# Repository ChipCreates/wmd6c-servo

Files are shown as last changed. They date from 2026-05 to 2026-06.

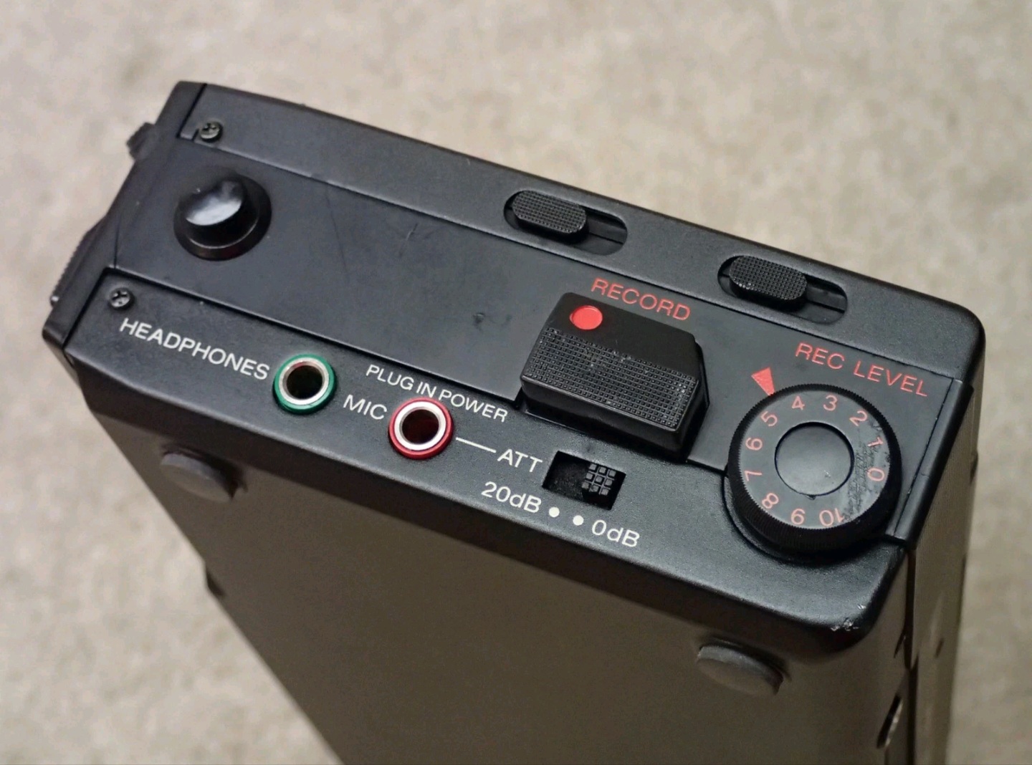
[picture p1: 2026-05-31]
docs/photos/overview/18-record-controls-audio-jacks.jpg

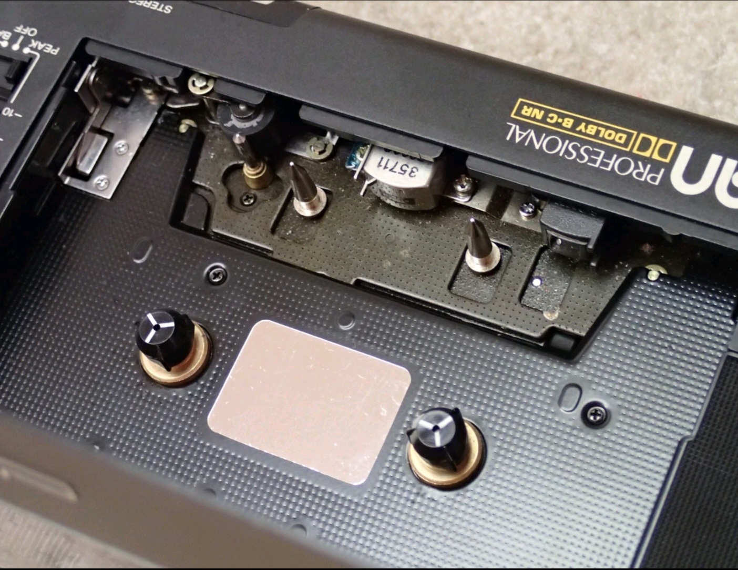
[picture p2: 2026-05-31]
docs/photos/overview/09-tape-mechanism-heads-closeup.jpg

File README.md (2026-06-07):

# wmd6c-servo — DSR-1

**Open-source / open-hardware servo, power, and USB-C service subsystem for the Sony Walkman WM-D6C / TC-D6C**

DSR-1 is an in-development replacement and modernization subsystem for the Sony WM-D6C / TC-D6C. Rev A targets the **CX20084 former-type servo family**, with the first physical unit identified as WM-D6C serial `72795`, PCB marking `C11-494-12`, and a surface-mount CX20084 at IC601. Its purpose is to preserve machines by replacing the fragile capstan-servo IC path, modernizing the external power interface, and adding USB-C data/service access for tuning, telemetry, firmware update, and diagnostics.

This project is not yet a finished installation-ready repair. It is currently in **source-grounded design and firmware-prototype development**. The firmware architecture exists, the KiCad files are in-flight and not yet synchronized with the latest documentation, and the design is being revised against the Sony WM-D6C/TC-D6C service manual and the selected STM32G0C1KCU6 device. PCB layout, hardware validation, installation documentation, and performance testing remain pending.

DSR-1 should be understood as an integrated two-board subsystem project, not a servo-only daughterboard: a **Power Board** and a **Servo Control Board**.

---

## Project Intent

The Sony WM-D6C is a professional-grade portable cassette recorder with a quartz-lock capstan servo system, excellent speed stability, and a transport worth preserving. Many surviving units are threatened by failures in and around the servo and power-input circuitry:

- **CX20084 / IC601 servo failure** — the original capstan-servo IC is obsolete and difficult to source reliably.
- **CN301 external power risk** — the original DC input arrangement is vulnerable to wrong-adapter failures.
- **CP304 / power-support aging** — the surrounding DC-DC and power-support circuitry is now decades old.
- **Serviceability limits** — the original analog servo has limited internal observability and cannot easily expose measured FG period, loop error, correction output, or tuning state.
- **Modern service access gap** — the original machine has no digital tuning, telemetry, firmware update path, or structured diagnostic interface.

DSR-1 aims to make the WM-D6C repairable without reducing it to a generic motor controller. The goal is not to modernize for its own sake. The goal is to preserve the machine by replacing an increasingly fragile control and power-support subsystem with one that can be measured, tuned, documented, powered safely, and reproduced.

---

## Current Status

**Status: active design / firmware prototype. Not bench-validated. Not ready for installation in a valuable machine.**

| Area | Status |
|---|---|
| Architecture | Defined at a high level |
| Sony service-manual review | In progress |
| STM32G0C1KCU6 package/pinout review | Accepted baseline; firmware migration pending |
| Firmware prototype | Register-level C source exists; bench validation pending |
| USB-C data/service path | Design requirement; validation pending |
| USB-C PD / power path | First-class design requirement; final implementation pending |
| KiCad schematic | In-flight legacy project exists; manual split to Power Board and Servo Control Board pending |
| PCB layout | Not complete |
| Bench measurements | Required before Rev A finalization |
| Installation guide | Planned; not yet valid for users |
| Pre-built module | Not available |
| Performance claims | Pending measured speed, power, USB, and wow/flutter data |

Until the electrical interface is measured on a real WM-D6C and a Rev A board is validated, DSR-1 should be treated as an engineering project, not a repair product.

---

## Compatibility Scope

DSR-1 targets the **full WM-D6C / TC-D6C production run (1984–2002)**. Two servo circuit families exist:

| Circuit family | Years | Servo IC | Rev A status |
|---|---|---|---|
| Ver. 1.0 | 1984 – mid 2001 | CX20084 | **Primary Rev A target** |
| Ver. 1.1 | mid 2001 – 2002 | CX-069A | Planned post-Rev A variant |

Rev A targets CX20084 boards — the large majority of surviving units. CX-069A board support is planned as a separate variant once Rev A is validated. See `docs/hardware/wmd6c-revision-compatibility.md` for detailed production timeline and identification guidance.

The primary unit currently being mapped is serial `72795`, observed PCB marking
`C11-494-12`, with a surface-mount CX20084 at IC601. Earlier assumptions that this
unit was a through-hole board are superseded.

---

## Governing References

Rev A is being grounded against these primary references:

1. **Sony WM-D6C / TC-D6C Service Manual, original edition (`fb4872.pdf`)**
   - Governing reference for Ver. 1.0 CX20084 servo circuit, component values, board layout, and tape speed calibration procedure.

2. **Sony WM-D6C / TC-D6C Service Manual, Ver. 1.1, 2001.06 (`sony_wm-d6c_tc-d6c_ver-1.1.pdf`)**
   - Documents the 2001 servo circuit change to CX-069A. Reference for Ver. 1.1 variant design (post Rev A).

3. **STMicroelectronics STM32G0C1KCU6 / STM32G0 family documentation**
   - Primary reference for MCU capabilities, electrical limits, package constraints, ADC/timer/USB/UCPD features, and operating conditions.

The repository documentation should distinguish clearly between:

- facts supported by the Sony service manual,
- facts supported by the selected STM32G0C1KCU6 package/device documentation,
- behavior implemented in source code,
- behavior measured on the bench,
- and design goals not yet proven.

---

## Design Position

DSR-1 is now scoped as an integrated two-board subsystem with three first-class domains:

| Domain | Purpose |
|---|---|
| Capstan servo | Replace the obsolete CX20084-based servo path with a measurable digital control loop |
| Power | Power Board for USB-C input, charger, LiPo/protection, regulation, and battery telemetry |
| USB-C data/service | Provide telemetry, live tuning, firmware update, diagnostics, and optional PD negotiation |

The servo loop remains the hardest performance-critical problem, but power and USB-C are not deferred side features. They are part of the Rev A architecture and must be represented in schematics, firmware, verification plans, and documentation.

---

## Known Target Unit Facts

The first physical target is a **former-type CX20084 WM-D6C**, not the 2001 CX-069A
new-type circuit.

| Machine / board | Current status |
|---|---|
| WM-D6C serial `72795` | Primary physical unit |
| PCB marking `C11-494-12` | Observed on the actual unit |
| IC601 | Surface-mount CX20084 |
| CX-069A boards | Planned post-Rev A variant only |
| WM-D6 | Future variant candidate only |
| WM-D3 / WM-D3C | Future variant candidate only |
| TC-D5M and related Sony professional machines | Future variant candidates only |

A variant port will require a schematic comparison, a harness/interface map, measured FG target data, power-interface notes, USB/service constraints, and proof of operation on physical hardware.

---

## What DSR-1 Is Intended to Replace or Add

The project boundary is larger than the CX20084 alone. The intended Rev A design work concerns the WM-D6C capstan-servo subsystem, the power path required to support it, and a USB-C service/data interface.

| Original function / missing function | DSR-1 design intent |
|---|---|
| CX20084 / IC601 capstan-servo function | STM32G0C1KCU6 digital PI servo loop using timer input capture |
| FG feedback path from motor / FG901 | Protected, conditioned MCU timer-capture input |
| Motor correction output to Sony drive network | PWM + RC filter + NPN level-shift to Q601 base; exact Q601 part/package pending physical confirmation |
| RV601 base speed adjustment | Retained as measured analog input |
| RV602 Speed Tune control | Retained as measured analog input |
| RV603 Speed Tune range control | Retained as measured analog input |
| S601 Speed Tune switch | Retained as digital input, polarity to be verified |
| S801 VU/BATT switch and D801-D805 LEDs | `S801_BATT` enables MCU battery-gauge ownership; MCU drives LEDs only in BATT mode and releases them in VU/non-BATT mode |
| CP304 / supporting power conversion | Replacement or support circuit pending Rev A power design |
| CN301 external power vulnerability | Protected input and/or USB-C power path |
| USB service interface absent in original | USB CDC / DFU / diagnostics / telemetry |
| USB-C PD absent in original | Power negotiation strategy, implementation pending |

The original transport, heads, audio path, user controls, and mechanical adjustment procedures should remain intact wherever possible.

---

## Architecture Overview

DSR-1 is designed around an STM32G0C1KCU6 microcontroller running register-level bare-metal C.

Planned/implemented firmware architecture:

- **FG measurement:** TIM2 input capture measures the period between FG pulses.
- **Servo loop:** PI control calculates motor correction from measured period error.
- **Output stage:** TIM3 PWM filtered through an RC network and NPN level-shift transistor (Q_LS MMBT3904) drives Q601's base on the WM-D6C main board.
- **Speed controls:** RV601/RV602/RV603 and S601 are retained and read by the MCU after voltage-safety verification.
- **USB data/service:** USB CDC is intended to expose live tuning, telemetry, command/status reporting, and diagnostics.
- **Firmware update:** USB DFU or other update path is intended to avoid requiring permanent SWD access after installation.
- **USB-C / power:** CC1/CC2 map to PA8/PA9. Variant A may use PD support; the battery build uses plain 5V USB-C into the Power Board charger.
- **Battery indicator:** In the battery build, the MCU reads `VBAT_SENSE`, `CHG_STAT`, `PGOOD`, and `S801_BATT`; it drives `BATT_LED1-5` only while S801 is in BATT.
- **Persistence:** Tuned constants are intended to be saved to flash with validation.
- **Debugging:** SWD remains available during development.

Important design caveat: the target period stored in flash is numerically stable, but final speed accuracy depends on the MCU timebase. The STM32 internal oscillator is suitable for firmware development, but final speed-performance claims require either a proven timing strategy, an external reference, calibration, or measured evidence that the selected clocking approach meets the WM-D6C speed requirements across realistic conditions.

---

## Rev A Engineering Priorities

The next project milestone is a source-grounded electrical interface and a bench-measured Rev A design covering servo, power, and USB-C.

Required before Rev A PCB finalization:

1. Map every DSR-1 signal to a Sony service-manual reference or a DSR-1-only service function.
2. Measure FG901 waveform voltage, offset, edge shape, noise, and frequency at correct speed.
3. Measure Q601 / motor-drive control voltage range during stop, startup, and play.
4. Measure RV601, RV602, and RV603 wiper voltage ranges and source behavior.
5. Verify S601 Speed Tune switch logic polarity and voltage.
6. Verify CN301 / battery / CP304 rail behavior under startup and play load.
7. Define the USB-C data/service connector role, ESD protection, shield/ground strategy, and firmware mode behavior.
8. Verify the S801 BATT-position sense, LED polarity/current limits, and CX10043 high-Z/release behavior before MCU LED ownership is finalized.
9. Decide the final servo timebase strategy.
10. Split and repopulate the KiCad schematic into the Power Board and Servo Control Board projects from measured interface requirements.
11. Validate power rails, reverse-polarity protection, USB enumeration, DFU/update behavior, and servo loop behavior before real-machine installation.
12. Publish measured speed, wow/flutter, power, and USB validation results before claiming original-equivalent or improved performance.

---

## Power and USB-C Strategy

Power and USB-C are part of the project scope.

| Function | Rev A intent |
|---|---|
| Protected external power | Required |
| Reverse-polarity protection | Required |
| Overcurrent / fault protection | Required |
| USB-C connector | Required for service/data; power role to be finalized |
| USB CDC telemetry | Required design goal |
| Firmware update path | Required design goal |
| USB-C PD | First-class design requirement; implementation architecture pending |
| Original barrel jack retention | Optional variant decision |
| CN301 replacement/removal | Optional variant decision |

Possible power approaches:

| | USB-C-centered variant | Protected barrel / hybrid variant |
|---|---|---|
| Power input | USB-C power path with PD strategy | Original-style or lab/protected input retained |
| User-facing behavior | Modern external power and data through USB-C | More conservative power bring-up |
| Complexity | Higher | Lower |
| Project status | In scope | In scope |

The preferred architecture should be selected by schematic feasibility, pin availability, installation constraints, safety behavior, and bench validation—not by minimizing scope.

---

## Repository Structure

```text
wmd6c-servo/
├── hardware/        KiCad project, schematic work, future PCB/BOM/gerbers
├── firmware/        Bare-metal STM32G0 family firmware prototype
├── docs/            Theory, datasheet references, installation and validation docs
└── tools/           Calibration and development utilities
```

Some paths and build commands are still being normalized as the project moves from design notes into a reproducible hardware/firmware package.

---

## Firmware Development

The firmware is written in C for the STM32G0 family, using CMSIS device headers and direct register access. The hardware target is STM32G0C1KCU6; some firmware filenames and comments may still reflect the earlier STM32G0B1KBU6 prototype until the firmware migration is completed. No STM32 HAL, no RTOS, and no dynamic memory allocation are intended.

Current firmware areas:

- `main.c` — clock setup, peripheral initialization order, main loop
- `servo.c` / `servo.h` — TIM2 capture ISR, PI loop, TIM3 PWM output path
- `adc.c` / `adc.h` — speed-control potentiometer scan and target adjustment support
- `flash.c` / `flash.h` — persistent settings storage
- `usb_cdc.c` / `usb_cdc.h` — USB CDC command and telemetry path
- `config.h` — tunable constants and hardware-selection flags

Firmware areas now required by project scope:

- USB CDC service and telemetry must remain isolated from the real-time servo loop.
- USB DFU or equivalent firmware update path must be documented and tested.
- USB-C attach/power-role behavior must be specified.
- If native STM32 UCPD is used, PD firmware must not compromise servo timing.
- If an external PD controller is used, firmware must define any required monitoring/control interface.
- Battery-gauge firmware must treat `S801_BATT` as the LED ownership enable and keep `BATT_LED1-5` released in VU/non-BATT modes.

Current firmware caveats:

- Bench validation has not yet been completed.
- The adjusted-target path from the analog speed controls must be verified end-to-end.
- The timebase decision remains open.
- USB-C PD implementation architecture remains open.
- Build layout and CI should be normalized before outside contributors rely on the firmware package.

See the firmware README for current build notes.

---

## Documentation Plan

The repository should grow toward the following documentation set:

```text
docs/
├── hardware/
│   ├── wmd6c-interface-contract.md
│   ├── wmd6c-revision-compatibility.md
│   ├── power-usb-c-architecture.md
│   └── timebase-decision.md
├── theory/
│   ├── original-servo-circuit.md
│   ├── digital-pll-servo.md
│   ├── signal-chain-analysis.md
│   └── power-supply-design.md
├── verification/
│   ├── 00-rev-a-bringup-checklist.md
│   ├── 01-wmd6c-preinstall-measurements.md
│   ├── 02-fg901-waveform-capture.md
│   ├── 03-motor-drive-characterization.md
│   ├── 04-speed-calibration-procedure.md
│   ├── 05-wow-flutter-test-plan.md
│   ├── 06-power-fault-test-plan.md
│   └── 07-usb-c-data-pd-test-plan.md
└── installation/
    └── planned after Rev A validation
```

Installation documentation should not be treated as valid until the hardware has been built, tested, photographed, and verified against the Sony adjustment procedure.

---

## Contributing

Contributions are welcome, but the project is still early enough that measurements and source-grounded review are more valuable than feature additions.

Most useful contributions right now:

- WM-D6C board-revision identification and photographs.
- Clear scans or notes that distinguish former/new servo circuit revisions.
- Bench measurements of FG901, Q601 motor-control behavior, RV601/RV602/RV603, S601, CP304, CN301, and original power rails.
- STM32G0C1KCU6 pinout and package review for servo, USB, UCPD, SWD, ADC, PWM, and timer conflicts.
- USB-C PD architecture review, including native UCPD versus external controller tradeoffs.
- Firmware review focused on interrupt timing, timer capture, ADC safety, flash behavior, USB CDC isolation, and PD interaction.
- KiCad schematic review once the Rev A sheets are populated.

Please see [CONTRIBUTING.md](CONTRIBUTING.md) for contribution expectations.

---

## License

| Artifact | License |
|---|---|
| Hardware design files | [CERN OHL-P v2](LICENSE_HARDWARE.txt) |
| Firmware source | [MIT](LICENSE) |
| Documentation | [CC BY 4.0](LICENSE_DOCS.txt) |

---

## Project Position

DSR-1 is being developed as a preservation-oriented engineering project. Its purpose is to make the WM-D6C repairable, measurable, maintainable, safely powered, and digitally serviceable without erasing what made the original machine worth saving.

Performance and safety claims will be earned by measurement, not assumed from architecture.

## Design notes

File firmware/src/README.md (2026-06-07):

# DSR-1 Firmware

Bare-metal C firmware for the WM-D6C DSR-1 Servo Control Board. The project
hardware target is STM32G0C1KCU6 at 64 MHz; this firmware tree still carries some
legacy STM32G0B1 build filenames until the firmware migration is completed. No HAL,
no RTOS, no dynamic memory allocation.

---

## Source Files

| File | Responsibility |
|---|---|
| `config.h` | All tunable constants — edit here and rebuild |
| `servo.c` / `servo.h` | TIM2 input capture ISR, PI control law, TIM3 PWM output |
| `adc.c` / `adc.h` | ADC DMA scan for RV601/RV602/RV603 pot wipers |
| `flash.c` / `flash.h` | Settings save/restore with CRC-32 validation |
| `usb_cdc.c` / `usb_cdc.h` | USB CDC virtual COM port, command parser, telemetry |
| `main.c` | Clock init (HSI16 → 64 MHz PLL), peripheral sequencing, main loop |

Build files live in `firmware/build/`:

| File | Responsibility |
|---|---|
| `Makefile` | `arm-none-eabi-gcc` build, flash/DFU targets |
| `STM32G0B1KBUx_FLASH.ld` | Legacy prototype linker script — to be replaced for STM32G0C1KCU6 |
| `startup_stm32g0b1xx.s` | Legacy prototype CMSIS startup — to be replaced for STM32G0C1KCU6 |

---

## Prerequisites

**Toolchain:** `arm-none-eabi-gcc` version 10.0 or newer.

```bash
# macOS
brew install --cask gcc-arm-embedded

# Ubuntu / Debian
sudo apt install gcc-arm-none-eabi

# Windows
# Download from https://developer.arm.com/downloads/-/gnu-rm
```

**CMSIS headers:** The STM32G0 CMSIS device headers (`stm32g0b1xx.h` etc.) must be on the include path. The Makefile searches three standard locations automatically. If not found, either:

- Set `CMSIS_DIR` on the command line (see below), or
- Copy the headers into `firmware/cmsis/` and the Makefile will find them

The headers ship with the [STM32CubeG0 package](https://www.st.com/en/embedded-software/stm32cubeg0.html) under `Drivers/CMSIS/`.

---

## Building

```bash
cd firmware/build

# Standard build — produces firmware.elf, firmware.bin, firmware.hex
make

# With explicit CMSIS path
make CMSIS_DIR=/path/to/STM32Cube_FW_G0_V1.6.1/Drivers/CMSIS

# Flash via SWD (requires openocd)
make flash

# Flash via USB DFU (device must be in DFU mode — hold TP1/BOOT0 while connecting USB)
make dfu

# Print section sizes
make size

# Generate annotated disassembly
make disasm

# Clean all build artefacts
make clean
```

The build prints a flash usage summary on completion. At the current firmware size of ~28 KB, there is approximately 98 KB of headroom against the 126 KB firmware budget (the last 2 KB page is reserved for the settings sector).

---

## Configuration

**`config.h` is the only file you should need to edit for normal configuration.** All machine-specific values, gain constants, and hardware limits are defined there. Never scatter tunable values through source files.

### Critical: TARGET_PERIOD_DEFAULT

This constant must be measured on the bench — the placeholder value will not be correct for every unit.

1. Insert test tape WS-48B, select Play mode
2. Connect oscilloscope to LINE OUT
3. Confirm 3 kHz tone = correct speed
4. Measure FG901 pulse frequency at that speed
5. Set `TARGET_PERIOD_DEFAULT = 64000000 / measured_Hz`
6. Rebuild and flash

Alternatively, use the `f+` / `f-` USB CDC commands to tune in real time without rebuilding, then `s` to save.

### Motor Output Stage

DSR-1 uses the **PWM + RC filter + NPN level-shift** output stage exclusively.
On the primary WM-D6C serial 72795 unit, Q601 is on the surface-mount
`C11-494-12` board and its exact package/marking plus base operating range remain
pending bench verification. Direct DAC drive is not used.

TIM3 channel 1 on PA6 produces the PWM signal. There is no `SERVO_OPTION_B`
define — the firmware is committed to this single output topology.

---

## USB CDC Live Tuning

The module enumerates as a virtual COM port on any computer without driver installation. Connect with any serial terminal at any baud rate (the baud rate setting is ignored — it is a USB CDC device).

| Command | Effect |
|---|---|
| `p+` / `p-` | Adjust Kp ±0.01 |
| `i+` / `i-` | Adjust Ki ±0.001 |
| `f+` / `f-` | Adjust target period ±1 tick |
| `t` | Print telemetry snapshot |
| `T` | Toggle continuous telemetry |
| `s` | Save current constants to flash |
| `r` | Restore compiled-in defaults (SRAM only — does not write flash) |
| `?` | Print command reference |

On first connection the firmware sends a banner confirming whether saved flash settings were loaded or defaults are active. If the banner shows a corruption warning, calibrate the unit and send `s` before use.

### Telemetry format

```
FG:25612 Hz:2499 Tgt:25600 Err:+12 Int:-847 PWM:2034 Kp:9830(0.150) Ki:524(0.008) RV1:2048 RV2:1923 RV3:2100
```

---

## Firmware Update (DFU)

The intended STM32G0C1KCU6 target contains a factory-programmed USB DFU bootloader.
To enter DFU mode:

1. Hold BOOT0 test point (TP1) to VDD
2. Connect USB-C cable
3. Release TP1

The device enumerates as a DFU device. Flash with:

```bash
# Using dfu-util (macOS/Linux)
dfu-util -d 0483:df11 -a 0 -s 0x08000000:leave -D firmware.bin

# Using STM32CubeProgrammer (Windows/macOS/Linux GUI)
# Select the .bin file, click Download
```

Pre-built `.bin` files for each release are in `firmware/releases/`.

> **Settings are preserved across DFU updates.** The settings sector (last 2 KB page at `0x0801F800`) is not erased by the update process.

---

## Architecture Notes

**Interrupt priorities** (lower number = higher priority on Cortex-M0+):

| Priority | Interrupt | Constraint |
|---|---|---|
| 0 | TIM2 (servo ISR) | Must preempt everything — non-negotiable |
| 1 | USB | Must not delay servo |

**Flash writes during playback:** The `s` command calls `servo_freeze()` before erasing flash and `servo_unfreeze()` after. The motor runs at constant open-loop drive for the ~2 ms erase window; the flywheel time constant (~200 ms) means speed does not measurably change. The servo re-locks within 1–2 FG periods after the write completes.

**No heap:** All memory is statically allocated. `_Min_Heap_Size = 0` in the linker script. `malloc` is not available and must not be added.

**Contributor rule:** All firmware contributions must use register-level C only. The STM32G0x1 Reference Manual (RM0444) and the selected STM32G0C1KCU6 datasheet are the authoritative sources — not the HAL API. See `docs/theory/why-bare-metal.md` for the full rationale.

---

## Licence

Firmware: MIT — see `LICENSE_FIRMWARE.txt`

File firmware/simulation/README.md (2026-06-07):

# DSR-1 Renode Simulation

Renode-based simulation for the DSR-1 firmware. The simulation platform still
models the earlier STM32G0B1 prototype until the firmware tree is migrated to the
STM32G0C1KCU6 hardware target.
Run from the **workspace root** (`d:/Projects/wmd6c-servo`).

## Prerequisites

**1. Install Renode** from https://renode.io. Packages are available for all
major platforms:

| Platform | Package |
|---|---|
| Windows | `.msi` installer (winget: `Antmicro.Renode`) |
| macOS | `.pkg` installer |
| Ubuntu / Debian | `.deb` — `sudo dpkg -i renode_*.deb` |
| Fedora / RHEL | `.rpm` — `sudo dnf install renode_*.rpm` |
| Any Linux | AppImage — `chmod +x renode_*.linux-portable` |

**2. Install renode-test Python dependencies.**

*Windows* — the default install path contains a space and must be quoted:
```
pip install -r "C:\Program Files\Renode\tests\requirements.txt"
```

*macOS / Debian / Ubuntu* — Renode installs to a path without spaces:
```
pip3 install -r /opt/renode/tests/requirements.txt
# macOS: /Applications/Renode.app/Contents/MacOS/tests/requirements.txt
```

*Fedora / RHEL* — same as Debian/Ubuntu but confirm the install prefix first:
```
renode --version          # shows install path
pip3 install -r /opt/renode/tests/requirements.txt
```

**3. Verify tools are on PATH** by opening a new terminal and running:
```
renode --version
renode-test --help
```

### VS Code terminal note (Windows only)

On Windows, VS Code's integrated terminal inherits the PATH from when VS Code
was launched, so tools installed afterward won't be found until VS Code is
restarted. The workspace `.vscode/settings.json` works around this for Windows
by appending the tool paths to every new VS Code terminal — open a **new
terminal** (`Ctrl+Shift+`\``) rather than reusing an existing one.

On Linux and macOS the system PATH is read fresh by each terminal and this is
not an issue.

## Quick start — interactive session

```
renode firmware/simulation/scripts/dsr1.resc
```

The Renode monitor (console) opens. The firmware is loaded and halted.

> **Do not call `start`.** The FG macros use `emulation RunFor` internally to
> advance simulation time in controlled steps. Calling `start` puts the emulation
> into free-run mode, which conflicts with `RunFor` inside a macro.

Load the FG helper and inject pulses — the macros start the CPU themselves:

```
(monitor) i @firmware/simulation/scripts/fg-gen.resc
(monitor) runMacro $fg_lock       # 10 nominal-speed pulses
(monitor) sysbus ReadDoubleWord 0x40000434   # read TIM3->CCR1 (motor PWM)
```

Each `runMacro $fg_lock` call steps the firmware through 10 FG edges, running
`clock_init` → `flash_load` → `adc_init` → `servo_init` → servo ISR on the way.
Expected TIM3->CCR1 ≈ 2048 (DAC_CENTER) when FG rate matches target exactly.

## Automated tests (Robot Framework)

```
renode-test firmware/simulation/tests/servo_loop.robot
```

Five tests:
1. **Boot completes** — firmware boots without hanging in any polling loop
2. **Nominal speed** — TIM3->CCR1 stays near DAC_CENTER at target FG rate
3. **Too slow** — motor drive increases (PWM decreases) when FG period is 110%
4. **Too fast** — motor drive decreases (PWM increases) when FG period is 90%
5. **Clamp check** — output stays within DAC_MIN/DAC_MAX at 200% slow
6. **Filter check** — sub-threshold periods (<6400 ticks) are discarded

## VS Code debugging

1. Start the Renode simulation (`dsr1.resc`), which opens GDB server on port 3333.
2. In VS Code: **Run → Start Debugging** → select **DSR-1: Debug via Renode**.
3. Set breakpoints in `servo.c`, `adc.c`, etc.
4. Use the Renode monitor alongside to inject FG pulses.

## FG injection reference

The servo ISR (`TIM2_IRQHandler`) reads `TIM2->CCR1` on every FG rising edge
and computes `period = CCR1 - last_capture`. To simulate one FG pulse from the
Renode monitor:

```
# Write a captured timestamp into CCR1 and fire the TIM2 IRQ
sysbus WriteDoubleWord 0x40000034 <CCR1_VALUE>   # TIM2->CCR1
sysbus WriteDoubleWord 0x40000010 0x00000002      # TIM2->SR: set CC1IF
sysbus WriteDoubleWord 0xE000E200 0x00008000      # NVIC_ISPR0: set IRQ 15 pending
```

Key values (see `firmware/src/config.h`):

| Constant | Value  | Meaning |
|---|---|---|
| TARGET_PERIOD_DEFAULT | 25600  | 2500 Hz at 64 MHz — nominal speed  |
| MIN_PERIOD_TICKS | 6400 | periods shorter than this filtered |
| DAC_CENTER | 2048 | TIM3 PWM at quiescent drive |
| DAC_MIN | 100 | maximum motor drive clamp |
| DAC_MAX | 3995 | minimum motor drive clamp |

To read the current motor PWM output:
```
sysbus ReadDoubleWord 0x40000434    # TIM3->CCR1
```

## Pot trim simulation

> **Note:** `SetVoltage` is not available on all Renode versions. Check with
> `help sysbus.adc` in the monitor. If present, set voltages with:
> ```
> sysbus.adc SetVoltage 1 <voltage>   # RV601 — base speed trim (PA1/ADC_IN1)
> sysbus.adc SetVoltage 2 <voltage>   # RV602 — Speed Tune slider (PA2/ADC_IN2)
> sysbus.adc SetVoltage 3 <voltage>   # RV603 — Speed Tune range (PA3/ADC_IN3)
> ```
> Mid-scale (1.65 V) = no offset. Full deflection (3.3 V or 0 V) = ±1% (RV601)
> or ±3% (RV602 at full range) speed trim.

This is moot until finding §3.3 is resolved — `adc_get_adjusted_target()` has no
caller, so ADC values have no effect on the servo loop in the current firmware.

To simulate the S601 Speed Tune enable switch being pressed (PA7 HIGH):
```
sysbus.gpioPortA SetData 0x0080 0x0080    # set PA7 high
```

## What a green run establishes — and what it does not

A passing run genuinely validates: the firmware boots through `clock_init` →
`flash_load` → `adc_init` → `servo_init` without deadlocking in a polling loop;
the PI arithmetic produces the right output for a given period delta; `DAC_MIN`
/ `DAC_MAX` clamp windup at the rails; `MIN_PERIOD_TICKS` discards short
periods; and the zero-error fixed point sits at `DAC_CENTER`. The control-law
math and structural plumbing are sound.

**Three things it does not establish:**

**1. Motor sign convention** (highest risk). The too-slow / too-fast direction
tests assert that a longer period lowers PWM and a shorter period raises it —
but they check the firmware against its own `config.h` convention with no
motor, no Q601, and no transistor network. If both the convention and the
control law were flipped together the tests would still pass; they were written
to match the code's current intent. Passing them is necessary but not
sufficient. The runaway risk on real silicon is exactly as open as it was before
the simulation existed. See `docs/hardware/motor-drive-sign-convention.md` and
close this only with a bench measurement of Q601 base voltage vs. motor speed.

**2. PA0 alternate function / FG acquisition path**. The simulation injects FG
by writing `TIM2->CCR1` + `CC1IF` + the NVIC pending bit directly, bypassing
the GPIO → AF-mux → input-capture path entirely. The wrong AF produces no
failure in simulation. On hardware, the wrong AF means `TIM2_CH1` is not
connected to PA0 and FG capture silently never fires. Finding 5.2 (PA0 should
be AF2, not AF1) has been fixed in `servo.c`, but the simulation cannot verify
that fix — only the bench can.

**3. Clock frequency correctness**. The RCC Python model releases the polling
loops by toggling ready bits; `PLLCFGR` writes fall through to the catch-all
and are never stored. A malformed PLL configuration (wrong multiplier or
divider) would pass the simulation and fail to lock on hardware. "Clock init
works" is a control-flow result, not a frequency-correctness one. Similarly,
the Renode timer model runs at 10 MHz while the firmware treats ticks as 64
MHz — the period math is internally consistent only because FG is injected as
absolute deltas; absolute timing is untested.

**Bench work the simulation cannot replace:** motor sign (requires Q601
measurement) and the FG acquisition front-end (AF wiring, input-capture
trigger, real FG frequency). These are the least-covered paths and the most
likely sources of a silent hardware failure.

---

## Known simulation limits

| Item | Status | Notes |
|---|---|---|
| Boot / init sequence | Works | All polling loops exit; clock_init, flash_load, adc_init, servo_init complete |
| PI control law | Verified | Period delta → PWM output correct; clamps and filter validated |
| Motor sign convention | **Not validated** | Tests are circular — check firmware against its own convention, not hardware physics; bench measurement required |
| PA0 AF (TIM2_CH1) | **Not caught by sim** | AF2 fix applied to servo.c (finding 5.2); GPIO→capture path never exercised in sim |
| Clock frequency (PLL) | Not validated | RCC model is control-flow only; PLLCFGR ignored; wrong multiplier/divider would pass |
| TIM2 input capture | Manual inject | Renode timer model does not support input capture; fg-gen.resc injects directly |
| TIM3 PWM output | Observable | Read TIM3->CCR1; absolute duty-cycle timing untested (10 MHz model vs. 64 MHz firmware) |
| Flash settings load | Works | Returns FLASH_ERR_INVALID (memory = 0x00), uses defaults |
| ADC calibration / ready loops | Likely works | Depends on STM32G0_ADC model clearing ADCAL and setting ADRDY |
| DMA ADC transfer | Partial | DMAMUX1 tagged; DMA→ADC circular transfer depends on STM32G0DMA model |
| Speed trim path (ADC→servo) | Moot | adc_get_adjusted_target() has no caller (finding 3.3); g_adc_raw[] not populated |
| USB CDC | Stubbed | Replaced with no-op stubs pending G0 USB_DRD port (finding 3.2) |
| Flash erase / write | Not tested | flash_save only reachable via USB CDC command; USB is stubbed |

## Platform file

`platform/stm32g0b1kbu6.repl` is derived from Renode's upstream
`platforms/cpus/stm32g0.repl` with three corrections for the G0B1 die:

- **RAM 144 KB** (upstream has 48 KB for smaller G0 variants)
- **Cortex-M0+** CPU type (upstream says cortex-m0)
- **64 MHz systick** (matching DSR-1 clock_init PLL target; upstream uses 72 MHz)

Plus a `DMAMUX1` tag at 0x40020800 to suppress access warnings from `adc_init`.

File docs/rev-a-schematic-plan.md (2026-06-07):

# Rev A Schematic Plan

**Project:** DSR-1 / wmd6c-servo  
**File:** `docs/hardware/rev-a-schematic-plan.md`  
**Status:** Legacy planning note / superseded by current two-board direction  
**Scope:** Historical schematic-structure planning, design gates, measurement dependencies, and Rev A acceptance criteria. Current implementation is being manually split into a Power Board and Servo Control Board; treat any all-in-one sheet structure below as legacy context unless it agrees with `PROJECT_STATUS.md`.

---

## 1. Purpose

This document defines the Rev A schematic plan for DSR-1.

The goal is to turn the project architecture into a KiCad schematic that can be reviewed, measured against, fabricated, brought up safely, and revised without ambiguity.

DSR-1 is an integrated subsystem project:

1. capstan servo,
2. power input/protection/support,
3. USB-C data/service,
4. USB-C PD or power-role strategy,
5. firmware update/debug,
6. and measurement/test access.

The schematic must reflect all of those domains. It must not be a servo-only schematic with power and USB added casually afterward.

---

## 2. Schematic Design Principles

Rev A schematic work follows these rules:

1. **No unmeasured Sony-facing node is final.**
2. **Every external input needs protection or a documented reason it does not.**
3. **Every motor-control state must fail safe.**
4. **USB-C data and power must not backfeed Sony rails unintentionally.**
5. **SWD/BOOT recovery must remain accessible.**
6. **The selected STM32 package must be proven by pin allocation before routing.**
7. **Every important signal needs a test point or measurement strategy.**
8. **Power, USB, servo, and analog references must be separated intentionally.**
9. **The schematic must encode the bring-up sequence.**
10. **Unsupported options must be marked DNP or moved out of Rev A.**

---

## 3. Required Source Documents

Before schematic acceptance, these documents must exist and be reviewed:

```text
docs/hardware/wmd6c-interface-contract.md
docs/hardware/power-usb-c-architecture.md
docs/hardware/timebase-decision.md
docs/hardware/wmd6c-revision-compatibility.md
docs/stm32g0c1-pin-allocation.md

docs/verification/00-rev-a-bringup-checklist.md
docs/verification/01-wmd6c-preinstall-measurements.md
docs/verification/02-fg901-waveform-capture.md
docs/verification/03-motor-drive-characterization.md
docs/verification/04-speed-calibration-procedure.md
docs/verification/05-wow-flutter-test-plan.md
docs/verification/06-power-fault-test-plan.md
docs/verification/07-usb-c-data-pd-test-plan.md
```

The schematic may begin before all measurements are complete, but any unmeasured area must be clearly marked as provisional.

---

## 4. Proposed KiCad Sheet Structure

Current manufacturing direction:

```text
hardware/power-board/
└── Power Board KiCad project

hardware/servo-control-board/
└── Servo Control Board KiCad project
```

The committed `hardware/kicad/DSR-1` project is in-flight legacy schematic work and
has not yet been updated to match the latest documentation.

---

## 5. Top-Level Sheet

### 5.1 `DSR-1.kicad_sch`

Responsibilities:

- show system-level sheet hierarchy,
- expose major nets,
- make power/servo/USB boundaries obvious,
- avoid hiding cross-domain dependencies.

Top-level net groups:

| Net group | Examples |
|---|---|
| Sony interface | `FG_IN_RAW`, `MOTOR_CTRL_OUT`, `RV601_WIPER`, `RAW_POWER`, `GND` |
| MCU local | `FG_IN`, `MOTOR_PWM`, `USB_DP`, `USB_DM`, `SWDIO`, `SWDCLK` |
| Power | `VBUS`, `RAW_POWER`, `+3V3`, `B_PLUS`, `MOTOR_SUPPLY` |
| USB-C | `USB_DP`, `USB_DM`, `CC1`, `CC2`, `USB_SHIELD` |
| Debug/test | `BOOT0`, `NRST`, `TP_*` |

Rules:

- Major domains must be readable from the top sheet.
- No hidden power nets without labels.
- Every inter-sheet net must use consistent naming.

---

## 6. Power Input / Protection Sheet

### 6.1 `01_power_input_protection.kicad_sch`

Responsibilities:

- external DC input, if retained,
- USB-C VBUS input handoff,
- battery/Sony rail interface,
- reverse-polarity protection,
- overcurrent protection,
- overvoltage protection,
- backfeed prevention.

Required blocks:

| Block | Status |
|---|---|
| CN301/protected external input option | Pending |
| USB-C VBUS input protection | Pending |
| Battery/Sony rail interface | Pending |
| Reverse-polarity protection | Pending |
| Overcurrent/fuse element | Pending |
| TVS/clamp strategy | Pending |
| Ideal diode / power mux strategy | Pending |
| Backfeed prevention | Pending |
| Test points | Required |

Design questions:

- Does USB-C replace CN301 or coexist?
- Does DSR-1 accept original external DC?
- Does DSR-1 support battery operation?
- Which source has priority?
- What rail powers the MCU in service-only mode?

Required test points:

- `TP_VBUS`,
- `TP_RAW_POWER`,
- `TP_PROTECTED_INPUT`,
- `TP_GND_POWER`,
- `TP_POWER_FAULT`.

---

## 7. Power Rails Sheet

### 7.1 `02_power_rails.kicad_sch`

Responsibilities:

- generate 3.3 V logic rail,
- generate or condition motor/support rail if required,
- provide rail sensing,
- provide power-good/fault status,
- ensure safe startup and shutdown.

Required blocks:

| Block | Status |
|---|---|
| 3.3 V regulator | Required |
| Motor/support rail generation or interface | Pending measurement |
| Rail sensing dividers | Recommended |
| Power-good signals | Recommended |
| Fault outputs | Recommended |
| Bulk/local decoupling | Required |
| Analog reference filtering | Required if ADC/PWM-filter sensing is sensitive |

Rules:

- Motor/switching currents must not share sensitive ADC/FG return paths.
- Regulator dropout and thermal behavior must be reviewed.
- Rail-sense dividers must not overvoltage ADC pins.
- DSR-1 must not backfeed Sony rails when unpowered.

Required test points:

- `TP_3V3`,
- `TP_MOTOR_SUPPLY`,
- `TP_B_PLUS`,
- `TP_B_PLUS_3`,
- `TP_GND_ANALOG`,
- `TP_GND_DIGITAL`.

---

## 8. USB-C Data / PD Sheet

### 8.1 `03_usb_c_data_pd.kicad_sch`

Responsibilities:

- USB-C connector,
- USB 2.0 FS D+/D− routing,
- ESD protection,
- VBUS sense/protection,
- CC1/CC2 handling,
- native UCPD or external PD controller,
- USB shield strategy.

Required blocks:

| Block | Status |
|---|---|
| USB-C receptacle | Required |
| D+/D− ESD protection | Required |
| VBUS ESD/protection | Required |
| CC1/CC2 strategy | Required |
| Native UCPD or external PD controller | Open decision |
| VBUS sense | Required |
| USB shield termination | Required decision |
| Service/data path to MCU | Required |

Native UCPD requirements:

- CC1/CC2 routed to valid MCU pins,
- firmware responsibility documented,
- default no-contract behavior safe.

External PD controller requirements:

- controller selected,
- default behavior documented,
- status/control pins assigned,
- output rail protected.

Rules:

- USB shield must not connect accidentally.
- USB ground must not inject motor/audio noise without review.
- USB attach must not enable motor output by default.
- USB D+/D− must be routed as USB signals, not casual GPIO.

Required test points:

- `TP_VBUS`,
- `TP_CC1`,
- `TP_CC2`,
- `TP_USB_DP`,
- `TP_USB_DM`,
- `TP_USB_SHIELD`,
- `TP_PD_STATUS`, if present.

---

## 9. MCU Sheet

### 9.1 `04_mcu_stm32g0c1.kicad_sch`

Responsibilities:

- STM32G0C1KCU6 MCU,
- decoupling,
- reset,
- BOOT0,
- SWD,
- clock/timebase pins,
- all assigned I/O,
- pin labels matching `docs/stm32g0c1-pin-allocation.md`.

Required blocks:

| Block | Status |
|---|---|
| MCU symbol/package | Pending final part |
| VDD/VDDA decoupling | Required |
| VREF+/analog reference handling | Required if used |
| NRST | Recommended |
| BOOT0 access | Required |
| SWDIO/SWDCLK | Required |
| USB pins | Required |
| UCPD pins, if native PD | Conditional |
| ADC inputs | Required |
| TIM3 PWM output (PA6) | Required |
| FG input | Required |
| Timebase option | Pending decision |

Rules:

- MCU package must match final pin-allocation document.
- Do not use family-level assumptions; verify exact package pins.
- SWD and BOOT access must remain available during Rev A.
- Reset/default pin states must not drive motor unsafely.

Required test points:

- `TP_SWDIO`,
- `TP_SWDCLK`,
- `TP_NRST`,
- `TP_BOOT0`,
- `TP_3V3_MCU`,
- selected spare GPIO if available.

---

## 10. FG Input Conditioning Sheet

### 10.1 `05_fg_input_conditioning.kicad_sch`

Responsibilities:

- accept raw FG signal from Sony motor/FG source,
- protect MCU input,
- condition waveform for timer capture,
- reject overvoltage/noise,
- support probing.

Possible blocks:

| Block | Use if |
|---|---|
| Series resistor/clamp | Mild protection sufficient |
| Divider | FG amplitude exceeds MCU range |
| Schmitt buffer | Edges are slow/noisy |
| Comparator | Analog waveform or shifting threshold needed |
| RC filter | High-frequency noise/ringing present |
| Pull-up/down | Source requires defined idle state |

Required input:

- result of `02-fg901-waveform-capture.md`.

Rules:

- Do not finalize conditioning without waveform measurements.
- Do not assume direct MCU input is safe.
- FG input must remain safe if Sony is powered and DSR-1 is unpowered.
- FG input must not load the original circuit significantly.

Required test points:

- `TP_FG_RAW`,
- `TP_FG_CONDITIONED`,
- `TP_FG_GND`.

---

## 11. Motor-Control Output Sheet

### 11.1 `06_motor_control_output.kicad_sch`

Responsibilities:

- generate motor-control correction signal,
- protect Sony motor-control node,
- protect STM32,
- provide safe reset/default state,
- implement PWM + RC filter + NPN level-shift output stage.

**Committed output architecture for Ver. 1.0 CX20084 boards:**

PWM + RC filter + NPN level-shift (TIM3_CH1 PA6 → R7/C8 → Q_LS MMBT3904 →
R9 pullup to B+1 → Q601 base). Q601 exact part/package and base operating range on
the C11-494-12 SMD board remain pending bench verification. Direct DAC drive is not
used.

Ver. 1.1 CX-069A board motor output architecture is not yet characterized and
is out of scope for Rev A.

Required input:

- result of `03-motor-drive-characterization.md`.

Rules:

- Motor output must be safe with MCU reset.
- Motor output must be safe in BOOT0/DFU mode.
- Motor output must be safe during USB attach/PD negotiation.
- Motor output must not backfeed Sony or MCU rails.
- Full output range must be testable with dummy load before Sony connection.

Required test points:

- `TP_MOTOR_CTRL_OUT`,
- `TP_MOTOR_CTRL_RAW`,
- `TP_MOTOR_ENABLE`,
- `TP_MOTOR_GND`.

---

## 12. Speed Controls / ADC Sheet

### 12.1 `07_speed_controls_adc.kicad_sch`

Responsibilities:

- accept RV601, RV602, RV603 wiper signals,
- accept S601 Speed Tune state,
- protect/scalefor MCU inputs,
- filter noise,
- preserve original behavior where practical.

Required signals:

| Signal | Function |
|---|---|
| `RV601_WIPER` | Base speed calibration |
| `RV602_WIPER` | User Speed Tune |
| `RV603_WIPER` | Speed Tune range |
| `S601_SPEED_TUNE` | Speed Tune enable |

Rules:

- No wiper connects directly to ADC until voltage range is measured.
- If source impedance is high, choose sampling time or buffer accordingly.
- Open/dirty pot states should fail safe in firmware and hardware where possible.
- S601 input must not float.

Required test points:

- `TP_RV601`,
- `TP_RV602`,
- `TP_RV603`,
- `TP_S601`.

---

## 13. Timebase Reference Sheet

### 13.1 `08_timebase_reference.kicad_sch`

Responsibilities:

- implement selected servo timebase strategy,
- optionally provide external/reference-derived clock,
- preserve future option if decision remains open.

Possible blocks:

| Block | Status |
|---|---|
| Internal oscillator only | Development possible, final not proven |
| External crystal | Candidate |
| External oscillator | Candidate |
| Sony-derived reference input | Candidate |
| Measurement/test point | Required for any external reference |

Required input:

- `docs/hardware/timebase-decision.md`.

Rules:

- Do not block external/reference-derived option before decision closes.
- If internal-only, document that final speed claims require measurement.
- Clock routing must avoid motor/USB noise.
- Timebase test point is strongly preferred.

Required test points:

- `TP_CLK_REF`,
- `TP_HSE_IN`, if present,
- `TP_SONY_REF`, if present.

---

## 14. Sony Interface Connector Sheet

### 14.1 `09_sony_interface_connector.kicad_sch`

Responsibilities:

- define physical/electrical connection to WM-D6C,
- collect Sony-facing harness signals,
- document direction and safety,
- support installation testing.

Required signals:

| Signal | Direction |
|---|---|
| `FG_IN_RAW` | Sony → DSR-1 |
| `MOTOR_CTRL_OUT` | DSR-1 → Sony |
| `RV601_WIPER` | Sony → DSR-1 |
| `RV602_WIPER` | Sony → DSR-1 |
| `RV603_WIPER` | Sony → DSR-1 |
| `S601_SPEED_TUNE` | Sony → DSR-1 |
| `RAW_POWER` | Power |
| `B_PLUS` | Power/sense |
| `B_PLUS_3` | Power/sense |
| `GND` | Reference |

Rules:

- Connector pinout must match interface contract.
- Harness direction must be obvious.
- Provide keyed connector if practical.
- Avoid pinout that can swap power and signal easily.
- Installation points must be documented with photos later.

Required test points:

- all Sony-facing signals should be accessible during Rev A bring-up.

---

## 15. Testpoints / Debug / Boot Sheet

### 15.1 `10_testpoints_debug_boot.kicad_sch`

Responsibilities:

- SWD,
- BOOT0,
- reset,
- test pads,
- manufacturing/bring-up access,
- optional jumpers/configuration straps.

Required access:

| Signal | Required |
|---|---:|
| SWDIO | Yes |
| SWDCLK | Yes |
| GND | Yes |
| 3.3 V reference | Yes |
| NRST | Strongly recommended |
| BOOT0 | Yes |
| UART debug | Optional |
| Power test points | Yes |
| FG test points | Yes |
| Motor output test points | Yes |
| USB/PD test points | Yes |

Rules:

- Debug access must remain possible on Rev A.
- BOOT0 access must be clearly labeled.
- Configuration jumpers must have safe defaults.
- Test points must not create accidental shorts during installation.

---

## 16. ERC / Review Requirements

Before PCB layout:

| Review | Required |
|---|---:|
| KiCad ERC clean or explained | Yes |
| Power net names reviewed | Yes |
| USB-C pins reviewed | Yes |
| MCU pin allocation reviewed | Yes |
| Sony-facing nets reviewed | Yes |
| Protection devices reviewed | Yes |
| Reset/safe states reviewed | Yes |
| Backfeed paths reviewed | Yes |
| Test points reviewed | Yes |
| DNP options documented | Yes |
| Measurement dependencies marked | Yes |

Every ERC waiver must be documented.

---

## 17. DNP and Option Strategy

Rev A may include optional footprints, but options must be controlled.

Possible DNP options:

| Option | Purpose |
|---|---|
| Variant A (USB-C PD) vs Variant B (barrel jack) | Power input selection |
| External oscillator footprint | Preserve timebase option |
| Native UCPD vs external PD controller | Evaluate PD architecture |
| Rail-sense dividers | Populate as needed |
| USB shield termination variants | Evaluate noise/ESD behavior |
| Pull-up/down variants | Match measured Sony signals |

Rules:

- DNP options must not create unsafe default behavior.
- Default population must be documented.
- Mutually exclusive options must be clearly marked.
- Jumpers/solder bridges must fail safe.

---

## 18. Rev A Schematic Acceptance Criteria

The Rev A schematic is accepted when:

| Requirement | Status |
|---|---|
| Sheet hierarchy complete | Pending |
| MCU package selected | Pending |
| Pin allocation accepted | Pending |
| Power input/protection complete | Pending |
| USB-C data/PD architecture complete | Pending |
| 3.3 V rail complete | Pending |
| FG input conditioning complete or measurement-pending marker present | Pending |
| Motor output complete or measurement-pending marker present | Pending |
| Speed-control input conditioning complete | Pending |
| Timebase strategy represented | Pending |
| Sony interface connector defined | Pending |
| SWD/BOOT/test access complete | Pending |
| Safe reset states reviewed | Pending |
| Backfeed prevention reviewed | Pending |
| Test points present | Pending |
| ERC passed or waived with notes | Pending |
| BOM generated | Pending |
| Schematic review logged | Pending |

---

## 19. Open Questions

1. ~~Is STM32G0B1KBU6 sufficient, or does Rev A need a larger package?~~ **Resolved: STM32G0C1KCU6 UFQFPN32.**
2. Is native UCPD feasible, or should Rev A use an external PD controller?
3. Does USB-C replace CN301 or coexist with it?
4. Does DSR-1 support battery-only operation?
5. Does DSR-1 generate motor/support rails or only interface with Sony rails?
6. ~~Is direct DAC motor output safe?~~ **Resolved: DAC is not used. PWM + NPN level-shift is the committed motor output for Ver. 1.0 boards.**
7. What FG conditioning is required? (Pending FG waveform measurement)
8. Is an external/reference-derived timebase required?
9. Where is USB-C mechanically mounted?
10. What connector/harness strategy is safest for Sony-facing signals?
11. Which optional footprints are worth carrying on Rev A?
12. What is the exact Q601 base voltage during playback? (Needed to confirm R9 sizing)

---

## 20. Final Rule

The Rev A schematic is not complete because every block has symbols.

It is complete only when every symbol reflects a measured requirement, a datasheet requirement, a safe default state, or a clearly marked validation assumption.

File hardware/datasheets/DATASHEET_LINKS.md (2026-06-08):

# Referenced Datasheets and Source Documents — WM-D6C DSR-1

**Project:** `ChipCreates/wmd6c-servo`  
**File:** `hardware/datasheets/DATASHEET_LINKS.md`  
**Status:** Aligned with the locked Power Board and Servo Board KiCad guides  
**Updated:** 2026-06-08

All linked documents remain the property of their respective manufacturers or
publishers. Links are provided for engineering reference only.

The DSR-1 design uses two physical boards:

- **Power Board:** USB-C 5 V/GND input, LiPo charging and protection, and regulated
  Sony `B+1` at 6.0 V.
- **Servo Board:** STM32, USB data/CC handling, local `+3V3`, `B+3`, servo control,
  Sony signal conditioning, SWD, and the mandatory LED battery monitor.

A link in this file does not by itself approve a part for the BOM. Parts marked
**baseline** are the current design basis. Parts marked **selection pending** require
an exact manufacturer, orderable part number, package, footprint, and datasheet review
before schematic freeze.

---

## 1. Document Authority

When sources disagree, use this order:

1. Bench measurements on the actual target WM-D6C.
2. Sony service manual matching the confirmed board family.
3. Exact manufacturer datasheet for the selected orderable component.
4. DSR-1 hardware guides and design notes.
5. Distributor-hosted datasheet mirrors.
6. Unverified third-party summaries.

The Rev A target is:

| Field | Value |
|---|---|
| Model | Sony WM-D6C |
| Serial number | 72795 |
| PCB marking | `C11-494-12` |
| Sony circuit family | Former type / Ver. 1.0 |
| Original servo IC | CX20084 |
| Primary Sony manual | Original/former-type service manual |

---

## 2. Primary MCU and STM32 Documentation

### Active baseline: STM32G0C1KCU6

| Document | Publisher | Document / status | Link |
|---|---|---|---|
| STM32G0C1xC/xE Datasheet | STMicroelectronics | **DS13564 Rev 5**; governs STM32G0C1KCU6 electrical limits, UFQFPN32 pinout, USB, UCPD, ADC, timers, and package data | https://www.st.com/resource/en/datasheet/stm32g0c1cc.pdf |
| STM32G0C1KC Product Page | STMicroelectronics | Exact device-family portal; includes STM32G0C1KCU6 ordering entry and current documentation | https://www.st.com/en/microcontrollers-microprocessors/stm32g0c1kc.html |
| STM32G0x1 Reference Manual | STMicroelectronics | RM0444; peripheral registers and operation | https://www.st.com/resource/en/reference_manual/rm0444-stm32g0x1-advanced-armbased-32bit-mcus-stmicroelectronics.pdf |
| STM32 Cortex-M0+ Programming Manual | STMicroelectronics | PM0223; Cortex-M0+ programming model | https://www.st.com/resource/en/programming_manual/pm0223-stm32-cortexm0-mcus-programming-manual-stmicroelectronics.pdf |
| USB Hardware and PCB Guidelines for STM32 MCUs | STMicroelectronics | AN4879; USB FS routing, ESD, clocking, power, and PCB guidance | https://www.st.com/resource/en/application_note/an4879-usb-hardware-and-pcb-guidelines-using-stm32-mcus-stmicroelectronics.pdf |

### MCU selection note

The selected Rev A part is **STM32G0C1KCU6**, not STM32G0B1KBU6 and not
STM32G0C1KCU6N.

The schematic symbol, pin mapping, package, and firmware configuration must all match
the exact non-`N` UFQFPN32 device. Recheck the exact package pin table before final
layout, especially:

- PA8 / CC1
- PA9 / CC2
- PA11 / USB_DM
- PA12 / USB_DP
- PA13 / SWDIO
- PA14-BOOT0 / SWDCLK
- exposed-pad VSS
- combined VDD/VDDA and VSS/VSSA pins

Use the ST product page to obtain the latest errata sheet before PCB release.

---

## 3. USB-C Data, CC, and ESD — Servo Board

The Servo Board owns USB D+/D−, CC1/CC2, USB protocol, firmware update, and SWD
recovery. The Power Board receives only USB-C 5 V and GND.

| Document | Manufacturer | Status | Link |
|---|---|---|---|
| USBLC6-2SC6Y ESD Protection | STMicroelectronics | **Baseline candidate** for USB D+/D− ESD protection; confirm package and placement | https://www.st.com/resource/en/datasheet/usblc6-2sc6y.pdf |
| STM32 USB Hardware and PCB Guidelines | STMicroelectronics | Required routing and ESD reference; also listed above | https://www.st.com/resource/en/application_note/an4879-usb-hardware-and-pcb-guidelines-using-stm32-mcus-stmicroelectronics.pdf |

### USB-C items still requiring exact part selection

No generic datasheet can replace the exact component datasheet for these items:

| Item | Requirement before schematic/BOM freeze |
|---|---|
| USB-C receptacle or panel connector | Select exact part; verify pin numbering, shield tabs, footprint, current rating, mating cycles, and mechanical fit |
| USB data inter-board flex/connector | Select exact part; verify USB 2.0 Full Speed suitability and ground-reference arrangement |
| CC1/CC2 protection | Select only after final CC/UCPD circuit is frozen |
| CC Rd resistors | Confirm resistance/tolerance from the final USB-C sink implementation |
| VBUS transient suppressor | Select exact 5 V-compatible device from surge/ESD requirements |
| Shield termination components | Freeze after chassis/EMC strategy is documented |

Rev A is a **5 V-only sink**. IP2721 and 9 V PD negotiation are not part of the
battery-integrated architecture.

---

## 4. Power Board — Charger and Power Path

### Active baseline: BQ24074

| Document | Manufacturer | Document / status | Link |
|---|---|---|---|
| BQ2407x Standalone 1-Cell 1.5-A Linear Battery Charger with PowerPath | Texas Instruments | **BQ24074 baseline**; Rev. N at time of this update | https://www.ti.com/lit/ds/symlink/bq24074.pdf |
| BQ24074 Product Page | Texas Instruments | Current product, package, tools, and documentation portal | https://www.ti.com/product/BQ24074 |

The exact BQ24074 orderable suffix and package must match the final KiCad symbol and
footprint.

The schematic review must cover all applicable pins and requirements, including:

- IN
- OUT
- BAT
- VSS and exposed thermal pad
- CE
- EN1 / EN2
- ISET
- ILIM
- TS
- TMR
- ITERM
- CHG
- PGOOD
- required IN, OUT, and BAT capacitors

Do not restore the superseded `800 ohm = 2 A` ILIM assumption. Program input and charge
current from the exact datasheet equations and the documented USB-C source capability.

---

## 5. Power Board — 1S3P Pack Protection

The design uses three 803040 LiPo cells in parallel as one logical 1S3P pack.

### Baseline protection topology; exact parts require BOM confirmation

| Document | Manufacturer | Status | Link |
|---|---|---|---|
| DW01A Single-Cell Li-Ion Protection IC | Fortune Semiconductor | **Baseline topology reference only**; confirm exact manufacturer and orderable part before use | https://www.ic-fortune.com/upload/Download/DW01A-DS-17_EN.pdf |
| FS8205A Dual N-Channel MOSFET | Fortune Semiconductor | **Baseline topology reference only**; Rev. 1.7 manufacturer datasheet | https://www.ic-fortune.com/upload/Download/FS8205A-DS-17_EN.pdf |

### Protection selection rules

- The selected protection IC and dual FET must be reviewed as a matched circuit.
- Copy the selected manufacturer's reference topology exactly.
- Verify overcharge, overdischarge, overcurrent, short-circuit, delay, and release
  thresholds against the selected cells.
- Confirm FET pinout and orientation against the exact package.
- Raw cell negative must not connect directly to system GND.
- If each purchased cell has an internal PCM, document how those PCMs interact with
  the board-level protection before deciding whether both remain populated.

### LiPo cell documentation required

The term `803040` describes dimensions, not a complete electrical specification.

Before ordering or PCB release, add the exact supplier datasheet for the selected cell,
including:

- manufacturer and orderable part number
- nominal and minimum capacity
- maximum continuous discharge current
- maximum charge current
- charge cutoff voltage
- discharge cutoff voltage
- internal protection, if any
- NTC, if any
- connector and wire gauge
- cell thickness tolerance
- swelling allowance
- cycle-life and temperature limits

---

## 6. Power Board — B+1 Buck-Boost

### Active baseline: TPS63070

| Document | Manufacturer | Document / status | Link |
|---|---|---|---|
| TPS63070 2-V to 16-V Buck-Boost Converter with 3.6-A Switch Current | Texas Instruments | **Baseline B+1 regulator**; Rev. B at time of this update | https://www.ti.com/lit/ds/symlink/tps63070.pdf |
| TPS63070 Product Page | Texas Instruments | Current product, package, design tools, and documentation portal | https://www.ti.com/product/TPS63070 |

The final schematic must explicitly handle:

- VIN pins
- VOUT pins
- L1 / L2
- FB and the 6.0 V divider
- FB2 / VSEL
- EN
- PS/SYNC
- VAUX
- PG
- GND and exposed pad
- input/output capacitance
- inductor saturation and RMS current
- startup and transient loading

Current target divider:

```text
R_TOP = 649 kΩ
R_BOTTOM = 100 kΩ

B+1 = 0.8 V × (1 + 649 kΩ / 100 kΩ)
    ≈ 6.0 V
```

The exact inductor, ceramic capacitors, and any bulk capacitor require their own
manufacturer datasheets before BOM freeze.

---

## 7. Servo Board — Local 3.3 V Regulator

### Baseline candidate: MCP1700-3302

| Document | Manufacturer | Document / status | Link |
|---|---|---|---|
| MCP1700 Low-Quiescent-Current LDO | Microchip Technology | **Baseline 3.3 V candidate**; DS20001826F | https://ww1.microchip.com/downloads/aemDocuments/documents/APID/ProductDocuments/DataSheets/MCP1700-Data-Sheet-20001826F.pdf |
| MCP1700 Product Page | Microchip Technology | Current ordering and documentation portal | https://www.microchip.com/en-us/product/mcp1700 |

Before locking MCP1700, calculate the complete 3.3 V current budget for:

- STM32 at maximum intended clock and peripheral activity
- USB operation
- status pull-ups
- signal-conditioning loads
- mandatory LED-interface circuitry
- SWD/debug activity
- margin for startup and future firmware behavior

Confirm that 6.0 V operation is acceptable at the selected load, including tolerance,
transients, and dissipation. The MCP1700 datasheet specifies 6.0 V as the upper end of
its normal input operating range, so B+1 tolerance and startup overshoot must be
included in this review.

---

## 8. Servo Board — B+3 Boost Converter

### Baseline candidate: MT3608

| Document | Manufacturer / source | Status | Link |
|---|---|---|---|
| MT3608 Boost Converter | XI'AN Aerosemi Tech; LCSC-hosted manufacturer datasheet mirror | **Baseline candidate**; verify exact supply source and marking | https://www.lcsc.com/datasheet/lcsc_datasheet_1811151539_XI-AN-Aerosemi-Tech-MT3608_C84817.pdf |

The final design must select exact orderable parts and datasheets for:

- MT3608 or replacement boost IC
- boost inductor
- boost rectifier
- input capacitors
- output capacitors
- feedback resistors

Current target output:

```text
B+1 ≈ 6.0 V
B+3 ≈ 10.8 V
R_TOP ≈ 169 kΩ
R_BOTTOM = 10 kΩ
```

The boost rectifier is **selection pending**. Do not treat `SS14` as approved merely
because it appeared in an earlier draft.

Because low-cost MT3608 supply chains can contain substitutions or questionable
markings, record the actual manufacturer/source used for prototypes.

---

## 9. Servo Board — Signal Conditioning and Motor Interface

### Baseline candidate devices

| Document | Manufacturer | Status | Link |
|---|---|---|---|
| MMBT3904 NPN Transistor | onsemi | **Baseline candidate** for the PWM level-shift stage | https://www.onsemi.com/pdf/datasheet/mmbt3904-d.pdf |
| BAT54S Dual Series Schottky Diode | Diodes Incorporated | **Baseline candidate** where a dual rail-clamp package is appropriate | https://www.diodes.com/assets/Datasheets/ds11005.pdf |

These links do not freeze the circuit values.

The following remain measurement-dependent:

- FG divider and clamp values
- motor-enable divider
- RV601/RV602/RV603 dividers and clamps
- Q601 base-interface resistors
- PWM filter values
- safe-off pull-up arrangement
- LED drive/buffer requirements

Do not select or size these components solely from generic example circuits.

---

## 10. Sony WM-D6C Source Documents

These are project source documents rather than manufacturer-hosted semiconductor
datasheets.

| Document | Role in Rev A |
|---|---|
| `fb4872.pdf` | **Governing Sony manual** for the former-type CX20084 circuit used by the target unit |
| `sony_wm-d6c_tc-d6c_ver-1.1.pdf` | Revision supplement used to distinguish former-type boards from the later CX-069A/Q601–Q605 circuit |
| `sony_wm-d6c_tc-d6c_ver-1.1_sm.pdf` | Alternate local filename for the same correct v1.1 PDF, if retained by the project source system |

### Confirmed target-board interpretation

The v1.1 manual's new/former-type discrimination identifies the
`1-611-494-12` family corresponding to PCB marking `C11-494-12` as former type.

Therefore Rev A uses:

- CX20084 former-type circuit
- single-Q601 control architecture
- original/former-type service manual as the primary Sony schematic

The later CX-069A/Q601–Q605 circuit is not a source for Rev A interface values.

### Sony components without reliable public datasheets

| Component | Treatment |
|---|---|
| CX20084 | Proprietary Sony servo ASIC; use service manual and bench measurements |
| CP304 | Proprietary/potted Sony DC-DC converter; use service manual interface data |
| CX10043 | Use Sony LED/VU schematic and bench measurements |
| FG901 / GP2S22AB | Use Sony schematic plus measured waveform and source impedance |
| Q601 | Service manual establishes a PNP control path, but exact SMD marking/package on serial 72795 must be physically confirmed before linking an external transistor datasheet |

Do not retain the previous unverified `2SB1013` Q601 entry as an approved Rev A part.

---

## 11. Mandatory LED Battery Monitor References

The LED battery monitor is part of the Rev A design, not an option.

Its electrical design depends primarily on:

- Sony service-manual schematic for D801–D805, R814–R818, IC801/CX10043, Q801, and S801
- STM32G0C1 GPIO electrical limits
- measured LED polarity and current
- measured CX10043 behavior in BATT mode
- the exact buffer transistor or MOSFET datasheet, if direct STM32 drive is not safe

No LED buffer part is approved yet. Add the exact buffer-device datasheet after bench
characterization determines whether the STM32 can safely drive or release the five
lines without contention.

---

## 12. Connectors and Mechanical Parts Requiring Exact Datasheets

Add exact manufacturer datasheets before PCB layout for:

| Item | Required review |
|---|---|
| USB-C receptacle | Pin numbering, shell, footprint, current, mechanical life |
| USB power harness to Power Board | Current rating, polarization, wire gauge |
| USB data/CC harness or flex to Servo Board | USB FS suitability, ground reference, impedance, length |
| Power Board telemetry connector | Pin current, pitch, latching, polarization |
| CP304 replacement connector/harness | Physical pinout, current rating, fit |
| Sony servo-interface harness | Pinout, pitch, retention, installation clearance |
| LED-board harness | Pinout, current, retention |
| SWD/Tag-Connect footprint | Exact cable and footprint drawing |
| Cell connectors | Current rating, polarization, mating cycles, wire size |

Generic connector-family names are not enough to approve footprints.

---

## 13. Removed or Superseded Rev A Components

The following parts belonged to earlier wall-power or all-in-one architectures and
are not active Rev A battery-build components:

| Component / block | Rev A status |
|---|---|
| STM32G0B1KBU6 | Superseded by STM32G0C1KCU6 |
| IP2721 USB PD trigger | Removed; Rev A is 5 V only |
| LTC4359 barrel-jack polarity protection | Removed with barrel-jack architecture |
| AP63203 buck regulator | Removed |
| Servo-board B+1 generator | Removed; Power Board generates B+1 |
| Power-board MT3608 | Removed; B+3 generation belongs on Servo Board |
| Power-board MCP1700 | Removed; +3V3 generation belongs on Servo Board |
| 9 V PD rail | Removed |
| SMBJ7.0A from the old barrel-jack path | Not part of current Rev A baseline |

Links for these parts are intentionally omitted from the active sections to avoid
accidental reuse.

---

## 14. Datasheet Capture Checklist

Before a component becomes BOM-approved:

- [ ] Exact manufacturer is recorded.
- [ ] Exact orderable part number is recorded.
- [ ] Package suffix matches the schematic symbol and footprint.
- [ ] Manufacturer datasheet is linked.
- [ ] Absolute maximum ratings are checked.
- [ ] Normal operating range is checked.
- [ ] Pinout is checked against the KiCad symbol.
- [ ] Recommended external components are checked.
- [ ] Thermal requirements are checked.
- [ ] Startup, shutdown, and unpowered behavior are checked.
- [ ] Reverse-current and back-power paths are checked.
- [ ] Component tolerances are included in calculations.
- [ ] Bench-test requirements are recorded.
- [ ] Distributor-only mirrors are identified as mirrors.
- [ ] Selection-pending parts are not presented as final.

---

## 15. License and Attribution

All linked documents are subject to their respective owners' copyright and terms of
use. Links are provided solely for engineering reference. No endorsement by Sony,
STMicroelectronics, Texas Instruments, Microchip Technology, Fortune Semiconductor,
onsemi, Diodes Incorporated, XI'AN Aerosemi Tech, or any distributor is implied.

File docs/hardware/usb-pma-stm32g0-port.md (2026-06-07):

# USB PMA Port — STM32G0 Second-Generation USB IP

**Project:** DSR-1 / wmd6c-servo
**File:** `docs/hardware/usb-pma-stm32g0-port.md`
**Status:** Defect note + porting guidance / pre-Rev A
**Scope:** Why the current `usb_cdc.c` packet-memory-area (PMA) access is wrong for
the STM32G0x1 USB device IP used by the selected STM32G0C1KCU6 target, what differs
between the two ST USB device IP generations, and the concrete changes required.
Register names and offsets below must be confirmed against RM0444 before relying on
this note.

---

## 1. Problem statement

`firmware/src/usb_cdc.c` accesses the USB packet memory area and buffer descriptor
table using the **first-generation** ST USB device convention. The selected
STM32G0C1KCU6 target uses the **second-generation** STM32G0x1 device IP, which
accesses the PMA differently. The code
will not enumerate as written.

The two affected constructs:

```c
/* ×2 stride — first-generation "doubled" PMA access */
static inline void pma_write16(uint32_t pma_off, uint16_t val) {
    *(__IO uint16_t *)(USB_PMA_BASE + pma_off * 2) = val;
}

/* Gap halfword after every real field — first-generation descriptor layout */
typedef struct {
    volatile uint16_t ADDR_TX;  uint16_t _pad0;
    volatile uint16_t COUNT_TX; uint16_t _pad1;
    volatile uint16_t ADDR_RX;  uint16_t _pad2;
    volatile uint16_t COUNT_RX; uint16_t _pad3;
} PMA_BufDesc;
```

---

## 2. The two USB IP generations

ST has shipped two generations of the (non-OTG) USB device peripheral. They differ
in how the CPU sees the PMA:

| Aspect | First generation | Second generation |
|---|---|---|
| Example parts | STM32F102/F103, L0, F0, F3, L4x2/x3, L5, **G4**, WB55 | **STM32G0**, C0, U0, U535/545, H503/23/33/63/73 |
| PMA access from CPU | 16-bit words mapped onto 32-bit boundaries ("2×16-bit/word"): a gap word sits between each real 16-bit word | Linear 1:1: 16-bit words are contiguous in the address space |
| Descriptor table stride | Doubled (each 16-bit field occupies 4 bytes of CPU address space) | Native (each 16-bit field occupies 2 bytes) |
| Effect on this code | Matches the `×2` stride and `_pad` words | Both the `×2` stride and the `_pad` words are wrong |

Practical consequence: on the G0, a 16-bit PMA word at PMA offset `N` (bytes) lives
at `USB_SRAM_BASE + N`, and the buffer descriptor entries are packed contiguously
with no padding. The current code writes to the wrong addresses and leaves
unwritten gaps the hardware does not expect.

> This is a documented IP-generation difference, not a board-specific quirk. It is
> the single reason the present USB layer cannot work on the selected STM32G0C1KCU6 target, independent
> of any descriptor or endpoint-state-machine issues.

---

## 3. Required changes

### 3.1 PMA base and access

Confirm the USB SRAM base for the G0 device IP from RM0444 (the legacy
`0x40006000` F1 base does not apply). Then drop the stride doubling:

```c
/* STM32G0: PMA is accessed linearly (1:1). Verify USB_SRAM_BASE in RM0444. */
#define USB_SRAM_BASE   0x40009800UL   /* <-- confirm against RM0444 */

static inline void pma_write16(uint32_t pma_off, uint16_t val) {
    *(__IO uint16_t *)(USB_SRAM_BASE + pma_off) = val;   /* no ×2 */
}
static inline uint16_t pma_read16(uint32_t pma_off) {
    return *(__IO uint16_t *)(USB_SRAM_BASE + pma_off);  /* no ×2 */
}
```

`pma_write_buf()` / `pma_read_buf()` keep their halfword-packing logic, but the
inner `pma_write16(pma_off + i*2, …)` offset arithmetic is now in real bytes, which
is what you want — just verify the `+ i*2` still indexes contiguous halfwords once
the stride doubling is removed.

### 3.2 Buffer descriptor table

Remove the gap words; the second-generation descriptor entries are contiguous
16-bit values:

```c
/* STM32G0: contiguous 16-bit descriptor fields, no padding. */
typedef struct __attribute__((packed)) {
    volatile uint16_t ADDR_TX;
    volatile uint16_t COUNT_TX;
    volatile uint16_t ADDR_RX;
    volatile uint16_t COUNT_RX;
} PMA_BufDesc;
```

The `COUNT_RX` field encodes the allocated buffer size via the block-size
(`BLSIZE`) and number-of-blocks (`NUM_BLOCK`) fields. Confirm the exact bit layout
in RM0444 — for a 64-byte endpoint it is typically `BLSIZE=1` (32-byte blocks) with
`NUM_BLOCK=1`, but verify rather than copy a first-generation value.

### 3.3 Endpoint / channel registers (verify together)

The second-generation IP also renames and reworks the per-endpoint registers
(channel/endpoint registers and their toggle-bit semantics) relative to the classic
`EPnR`. Before declaring USB done, check against RM0444:

- the per-endpoint register name and the read-modify-write toggle/clear semantics
  (the "write-1-to-toggle, write-0-to-leave" behavior is easy to get subtly wrong),
- the `BTABLE` location/programming,
- the control register and interrupt-status register field names,
- whether any USB SRAM clock/isolation or transceiver-enable bit must be set that
  the first-generation flow did not require.

### 3.4 Things that do not change

- The descriptor *contents* (device/config/CDC class descriptors) are USB-spec
  level and are unaffected by the PMA model.
- The crystal-less clocking plan (HSI48 + CRS) is independent of PMA access and
  remains valid; see `docs/theory/usb-crystalless-operation.md`.
- The priority-1 USB / priority-0 servo split is unaffected.

---

## 4. Validation

Fold these into `docs/verification/07-usb-c-data-pd-test-plan.md`:

1. Device enumerates as a CDC ACM virtual COM port on Linux, macOS, and Windows
   with no driver install.
2. The boot banner is received intact on first connection (exercises an EP1-IN
   transfer through the rewritten PMA path).
3. A host→device command (`t`) returns a correctly framed telemetry line
   (exercises EP2-OUT and the RX descriptor).
4. Sustained continuous telemetry (`T`) at the configured interval shows no
   dropped or corrupted lines (exercises descriptor turnaround and COUNT fields).
5. With telemetry streaming, confirm on the scope that the servo timing on the
   FG-derived PWM output is undisturbed (priority hierarchy intact).

---

## 5. Open question

Decide whether to keep a hand-written register-level USB stack or adopt a small
vetted bare-metal CDC implementation already validated on the STM32G0 second-gen IP.
The project's "register-level, RM0444-authoritative" rule favors keeping it
in-house, but the PMA and endpoint-register rewrite is exactly the area where a
known-good reference saves the most bring-up time. Either way, the result must be
register-level and HAL-free per the contributor rule.

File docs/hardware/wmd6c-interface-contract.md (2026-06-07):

# WM-D6C Interface Contract

**Project:** DSR-1 / wmd6c-servo  
**File:** `docs/hardware/wmd6c-interface-contract.md`  
**Status:** Draft / pre-Rev A  
**Purpose:** Define the electrical, power, USB-C, mechanical, and service interface between the Sony WM-D6C/TC-D6C and the DSR-1 Power Board / Servo Control Board subsystem.

---

## 1. Purpose

This document is the hardware interface contract between the Sony WM-D6C/TC-D6C and the DSR-1 digital servo, power, and USB-C service module.

DSR-1 is not being scoped as a servo-only daughterboard. The Rev A design must treat the following as first-class project domains:

1. **Capstan servo replacement**
2. **Power-input and power-support modernization**
3. **USB-C data/service interface**
4. **USB-C PD or USB-C power-role strategy**

The project must not proceed from concept to PCB layout by assumption. Every signal that crosses the boundary between the Sony machine and the DSR-1 boards must be identified, measured, documented, and justified against the source material and bench data.

This file answers five questions for every interface signal:

1. **What Sony circuit node or DSR-1 service node does this connect to?**
2. **What does that node do in the original or new system?**
3. **What electrical limits must DSR-1 obey?**
4. **What firmware behavior is required?**
5. **What bench measurements are required before Rev A hardware can be finalized?**

This document is not a tutorial and not a theory document. It is a design-control document.

---

## 2. Governing References

### 2.1 For Ver. 1.0 Boards (CX20084, 1984 – mid 2001) — Rev A Primary Target

1. **Sony WM-D6C / TC-D6C Service Manual, original edition (`fb4872.pdf`)**
   - Used for the CX20084 servo circuit schematic, component values, board layout, adjustment procedures, and tape speed calibration procedure.
   - This is the governing servo-circuit reference for all CX20084 boards, including the primary test unit (serial 72795, ~1987).

2. **STMicroelectronics STM32G0C1KCU6 / STM32G0 family documentation**
   - Used for MCU electrical limits, ADC constraints, timer capability, PWM output, USB, UCPD, package limitations, and operating conditions.

3. **Bench measurements from physical WM-D6C units**
   - Required for final signal voltage ranges, waveform shape, noise behavior, source impedance, motor-control behavior, power-rail behavior, and safe interface design.

### 2.2 For Ver. 1.1 Boards (CX-069A, mid 2001 – 2002) — Planned Variant

4. **Sony WM-D6C / TC-D6C Service Manual, Ver. 1.1, 2001.06 (`sony_wm-d6c_tc-d6c_ver-1.1.pdf`)**
   - Documents the servo circuit change (ECN-WMA00831) to CX-069A + five-transistor motor drive.
   - Governing reference for Ver. 1.1 board variant design (post Rev A).

### 2.3 Authority Order

If sources conflict:

1. Bench measurement on the actual target unit.
2. Service manual appropriate to the confirmed board revision.
3. STM32G0C1KCU6 package/device documentation.
4. DSR-1 design assumptions.

Assumptions must never be treated as measured facts.

---

## 3. Design Scope

DSR-1 has three first-class interface domains.

| Domain | Scope |
|---|---|
| Servo | FG input, motor-control output, speed-control inputs, servo timing, telemetry |
| Power | CN301/battery/CP304 behavior, protected input, power rails, fault protection |
| USB-C data / PD | USB data, telemetry, firmware update, diagnostics, optional/native PD, connector behavior |

The servo remains performance-critical, but power and USB-C are not optional documentation afterthoughts. They must appear in the schematic, pinout, verification plan, and firmware architecture.

---

## 4. Compatibility Scope

DSR-1 targets the **full WM-D6C / TC-D6C production run (1984–2002)**.

### 4.1 Rev A Primary Target

| Target | Status |
|---|---|
| WM-D6C / TC-D6C Ver. 1.0 CX20084 boards (1984 – mid 2001) | **Rev A primary target** |

Rev A targets CX20084 boards. This covers the majority of surviving and
collector-held units across the full production run prior to the 2001 servo
circuit change.

Primary test unit: serial 72795, observed PCB marking C11-494-12, surface-mount
CX20084 confirmed at IC601, rounded amorphous 35711 head confirmed.

### 4.2 Planned Variants

| Machine / revision | Status |
|---|---|
| WM-D6C / TC-D6C Ver. 1.1 CX-069A boards (mid 2001 – 2002) | **In scope — planned post-Rev A variant** |
| WM-D6 | Future variant candidate |
| WM-D3 / WM-D3C | Future variant candidate |
| TC-D5M and related Sony professional machines | Future variant candidate |

A planned variant requires its own schematic comparison, harness map, motor-drive
characterization, power-interface characterization, USB/service constraints, and
physical-unit validation before it may be called supported.

---

## 5. Test Unit Identification

Each physical machine used for measurements must be logged.

### Current Known Unit

| Field | Value |
|---|---|
| Model | Sony WM-D6C |
| Serial number | 72795 |
| Serial-number source | Battery-compartment label photo |
| Board revision | Pending internal inspection |
| Servo circuit revision | Pending comparison against service-manual schematic |
| Power-path condition | Pending inspection |
| CN301 condition | Pending inspection |
| CP304 condition | Pending inspection |
| Measurement status | Not yet measured |

The serial number identifies the unit, but it does **not** prove the board revision, servo-circuit revision, or power-path condition. Internal board photographs and schematic comparison are still required.

---

## 6. Boundary Definition

DSR-1 replaces or interfaces with the capstan-servo subsystem, the power-support path, and the new USB-C service/power interface.

### 6.1 DSR-1 May Interface With

| Sony subsystem | Function |
|---|---|
| IC601 / CX20084 area | Original capstan-servo IC location / servo node access |
| M901 / FG901 | Motor and frequency-generator feedback |
| Q601 and surrounding motor-drive network | Capstan motor control path |
| RV601 | Base tape-speed adjustment |
| RV602 | User Speed Tune control |
| RV603 | Speed Tune range adjustment |
| S601 | Speed Tune on/off switch |
| CN301 | External DC input path |
| CP304 | DC-DC / power-support board |
| Battery rail | Portable power behavior |
| Ground / chassis reference | Electrical reference and shielding behavior |

### 6.2 DSR-1 Adds

| DSR-1-added subsystem | Function |
|---|---|
| USB-C connector | Service/data and possible power input |
| USB CDC interface | Telemetry, tuning, diagnostics |
| Firmware update path | DFU or equivalent update mechanism |
| USB-C PD strategy | Power negotiation, either native UCPD or external controller |
| Protection network | ESD, reverse-polarity, overcurrent, and overvoltage protections as required |

### 6.3 DSR-1 Should Preserve

| Original system | Preservation goal |
|---|---|
| Tape transport mechanics | No unnecessary mechanical modification |
| Audio signal path | No intentional modification |
| User controls | Preserve normal user-facing behavior |
| Sony adjustment procedure | Remain compatible where practical |
| Serviceability | Make the machine easier to diagnose, not harder |
| Portable behavior | Preserve safe battery and external-power operation where practical |

---

## 7. Signal Summary

| DSR-1 signal | Sony / DSR-1 reference area | Direction | Required before Rev A |
|---|---|---:|---|
| `FG_IN` | M901 / FG901 | Sony → DSR-1 | Waveform capture and voltage-range proof |
| `MOTOR_CTRL` | Q601 / motor-drive network | DSR-1 → Sony | Control-voltage and current characterization |
| `RV601_WIPER` | RV601 speed adjustment | Sony → DSR-1 | Wiper voltage range and source impedance |
| `RV602_WIPER` | RV602 Speed Tune | Sony → DSR-1 | Wiper voltage range and switch behavior |
| `RV603_WIPER` | RV603 Speed Tune range | Sony → DSR-1 | Wiper voltage range and scaling behavior |
| `S601_SPEED_TUNE` | S601 Speed Tune switch | Sony → DSR-1 | Logic polarity and voltage |
| `RAW_POWER` | CN301 / battery / CP304 region | Power | Polarity, voltage, surge, and load behavior |
| `B_PLUS` | Sony servo/motor rail | Power / sense | Voltage behavior during stop/start/play |
| `B_PLUS_3` | Sony regulated/support rail | Power / sense | Voltage and loading behavior |
| `GND` | Main board ground / chassis | Reference | Grounding and noise strategy |
| `USB_DP` / `USB_DM` | DSR-1 USB-C service interface | DSR-1 ↔ host | USB FS routing, ESD, firmware behavior |
| `USB_CC1` / `USB_CC2` | USB-C connector / UCPD or PD controller | DSR-1 ↔ source | Attach detection / PD strategy |
| `VBUS` | USB-C connector | Host/source → DSR-1 | Voltage, protection, power mux behavior |
| `USB_SHIELD` | USB-C shell / chassis strategy | Mechanical/electrical | Shield termination decision |
| `SWDIO` / `SWDCLK` | DSR-1 programming interface | DSR-1 ↔ programmer | Development access |
| `BOOT0` | DSR-1 boot control | Input | DFU/programming access |

Signal names may change as the schematic is finalized, but the contract must remain clear.

---

## 8. FG Feedback Interface

### 8.1 Signal Name

`FG_IN`

### 8.2 Sony Reference Area

| Sony reference | Meaning |
|---|---|
| M901 | Capstan motor assembly |
| FG901 | Frequency-generator feedback source |

### 8.3 Function

The original servo uses FG feedback from the motor/capstan system to determine actual tape speed. DSR-1 measures the FG period using an STM32 timer input-capture peripheral.

### 8.4 DSR-1 Design Intent

DSR-1 should condition the FG signal into a clean, safe logic-level input suitable for STM32 timer capture.

The firmware design assumes:

| Firmware assumption | Current status |
|---|---|
| FG pulse train is periodic at correct speed | Must be measured |
| FG period can be measured with TIM2 input capture | Implemented in firmware prototype |
| Approximate nominal FG rate is around 2500 Hz | Placeholder estimate only |
| Signal is safe for direct MCU input | Not assumed; must be proven |

### 8.5 Required Bench Measurements

| Measurement | Required result |
|---|---|
| FG waveform amplitude | Determine if direct input, divider, clamp, comparator, or Schmitt stage is required |
| FG DC offset | Ensure STM32 input limits are not violated |
| FG edge shape | Determine need for hysteresis / filtering |
| Noise / ringing | Determine conditioning and grounding strategy |
| FG frequency at correct tape speed | Establish target period |
| FG behavior during startup | Prevent false capture / unstable lock |
| FG behavior during stop / pause | Define firmware state handling |

### 8.6 Electrical Safety Rules

- Do not connect FG901 directly to an STM32 pin until voltage range is measured.
- If FG exceeds STM32 input limits, add conditioning.
- If FG is slow-edged or noisy, add hysteresis or comparator conditioning.
- If FG is referenced to a noisy motor ground, ground routing must be reviewed before PCB layout.

---

## 9. Motor-Control Interface

### 9.1 Signal Name

`MOTOR_CTRL`

### 9.2 Sony Reference Area

| Sony reference | Meaning |
|---|---|
| Q601 | Motor-control transistor / servo drive area |
| Q603–Q605 | Supporting motor-control network, pending schematic confirmation |
| M901 | Capstan motor |

### 9.3 Function

The original servo controls motor speed by applying a correction signal into the motor-drive network. DSR-1 must reproduce the control behavior without overdriving, loading, or destabilizing the Sony motor circuit.

### 9.4 DSR-1 Design Intent

DSR-1 uses a PWM + RC filter + NPN level-shift output stage (TIM3 CH1 on PA6).

Q601 on WM-D6C serial 72795 is on the surface-mount C11-494-12 board. Its exact
package/marking and base operating range are pending physical confirmation. Direct
DAC drive is not used; the NPN level-shift topology (Q_LS MMBT3904, R7–R9) is the
committed output design.

Bench measurement of the Q601 base voltage during playback is still required to
confirm R9 sizing and the PWM duty-cycle-to-speed mapping.

### 9.5 Required Bench Measurements

| Measurement | Required result |
|---|---|
| Q601 / motor-control voltage during stop | Determine safe inactive state |
| Motor-control voltage during startup | Determine transient behavior |
| Motor-control voltage during steady play | Determine operating point |
| Motor-control voltage during speed correction | Determine output range |
| Motor current at startup | Determine power-path and protection requirements |
| Motor current during steady play | Determine normal loading |
| Motor response to small control perturbations | Tune PI loop and output scaling |

### 9.6 Electrical Safety Rules

- The DSR-1 output must fail safe at reset.
- MCU reset, bootloader entry, firmware crash, USB connection, or PD negotiation must not drive the motor uncontrolled.
- A passive default state should hold the motor-control interface in a safe condition until firmware is active.
- The output stage must not backfeed Sony rails when DSR-1 is unpowered.
- Direct DAC drive is not used; control-node voltage measurements are for validating
  the committed PWM + NPN level-shift output stage.

---

## 10. Speed-Control Inputs

The WM-D6C speed-control network must be preserved where practical. DSR-1 should retain the original adjustment behavior instead of replacing it with firmware-only constants.

### 10.1 RV601 — Base Speed Adjustment

| Field | Value |
|---|---|
| DSR-1 signal | `RV601_WIPER` |
| Sony reference | RV601 |
| Direction | Sony → DSR-1 |
| Function | Base tape-speed calibration |

Required measurements:

- Minimum wiper voltage.
- Maximum wiper voltage.
- Center / nominal setting voltage.
- Source impedance.
- Noise while motor is running.
- Interaction with the rest of the speed-control network.

Safety rules:

- The wiper must not exceed STM32 ADC input limits.
- If voltage can exceed safe range, add scaling and protection.
- Firmware must not assume midscale until measured.

### 10.2 RV602 — User Speed Tune

| Field | Value |
|---|---|
| DSR-1 signal | `RV602_WIPER` |
| Sony reference | RV602 |
| Direction | Sony → DSR-1 |
| Function | User-accessible Speed Tune control |

Required measurements:

- Minimum wiper voltage.
- Maximum wiper voltage.
- Center detent or nominal user setting, if present.
- Behavior with S601 enabled.
- Behavior with S601 disabled.
- Effective speed range in the original circuit.

Safety rules:

- Preserve the user-facing Speed Tune function where practical.
- Do not allow disconnected or dirty potentiometer readings to command unsafe speed.
- Firmware should clamp adjusted target period to safe limits.

### 10.3 RV603 — Speed Tune Range

| Field | Value |
|---|---|
| DSR-1 signal | `RV603_WIPER` |
| Sony reference | RV603 |
| Direction | Sony → DSR-1 |
| Function | Sets Speed Tune range / sensitivity |

Required measurements:

- Minimum wiper voltage.
- Maximum wiper voltage.
- Relationship to RV602 effect.
- Whether the adjustment is factory-only or user-accessible.
- Whether the original range corresponds to the firmware scaling assumption.

Safety rules:

- Treat RV603 as calibration data, not a free-running user control, until confirmed.
- Firmware should bound the range contribution even if the pot is open or noisy.

---

## 11. Speed Tune Switch

### 11.1 Signal Name

`S601_SPEED_TUNE`

### 11.2 Sony Reference

`S601`

### 11.3 Function

S601 determines whether the Speed Tune function is active in the original circuit.

### 11.4 Required Bench Measurements

| Measurement | Required result |
|---|---|
| Switch logic when OFF | Determine pull direction |
| Switch logic when ON | Determine active polarity |
| Voltage level | Determine STM32 compatibility |
| Contact bounce | Determine firmware debounce need |
| Interaction with RV602/RV603 | Determine adjusted-target logic |

### 11.5 Safety Rules

- Do not assume active-high or active-low until measured.
- Use a defined pull-up or pull-down so the MCU input never floats.
- Firmware should default to normal calibrated speed if switch state is invalid.

---

## 12. Power Interface

### 12.1 Signals

| DSR-1 signal | Sony / connector reference area | Function |
|---|---|---|
| `RAW_POWER` | CN301 / battery path | Incoming supply |
| `B_PLUS` | Sony power rail | Servo/motor rail, exact role pending measurement |
| `B_PLUS_3` | Sony support rail | Regulated/support rail, exact role pending measurement |
| `VBUS` | USB-C connector | USB-C power input / attach detection |
| `GND` | Main board ground | Reference |

### 12.2 Design Intent

The power interface must support DSR-1, preserve the WM-D6C transport behavior, and eliminate or reduce the wrong-adapter failure mode associated with the original external DC input.

USB-C power and PD behavior are in scope. DSR-1 may ultimately use one of these architectures:

| Architecture | Description |
|---|---|
| Native STM32 UCPD | STM32G0C1 handles USB-C attach/PD functions directly |
| External PD controller | Dedicated PD trigger/controller negotiates power and presents a simpler rail to DSR-1 |
| Hybrid protected input | USB-C data/service is required while external power strategy remains protected barrel/lab input for early Rev A |
| Dual-path | USB-C and protected barrel input coexist with a defined mux/protection strategy |

The architecture must be selected by pin availability, firmware complexity, safety behavior, layout feasibility, and bench validation.

### 12.3 Required Bench Measurements

| Measurement | Required result |
|---|---|
| CN301 polarity and voltage | Confirm original external power behavior |
| Battery rail voltage | Determine operating range |
| CP304 output behavior | Determine replacement/support requirement |
| Startup current | Size protection and conversion components |
| Steady-play current | Size normal operation |
| Motor transient current | Confirm surge margin |
| Reverse-polarity event behavior | Define protection test |
| Overvoltage event behavior | Define protection test |
| USB VBUS behavior | Define allowed power states |
| USB attach behavior | Define firmware/power sequencing |

### 12.4 Safety Rules

- DSR-1 must not make the external power failure mode worse.
- Reverse polarity protection must be verified, not merely assumed.
- Overvoltage behavior must be tested with current-limited supplies.
- DSR-1 must not backfeed Sony rails when unpowered.
- USB, SWD, battery, and external power paths must not create unintended power injection.
- PD negotiation failure must leave the machine in a safe state.
- USB connection for data alone must not unexpectedly power the motor path unless explicitly designed.

---

## 13. USB-C Data / Service Interface

### 13.1 Signals

| DSR-1 signal | Function |
|---|---|
| `USB_DP` | USB 2.0 FS D+ |
| `USB_DM` | USB 2.0 FS D- |
| `USB_CC1` | USB-C configuration / PD channel |
| `USB_CC2` | USB-C configuration / PD channel |
| `VBUS` | USB-C bus voltage |
| `USB_SHIELD` | Connector shell / shield strategy |
| `GND` | USB reference and system ground relationship |

### 13.2 Required Functions

The USB-C service interface should support:

| Function | Requirement |
|---|---|
| Telemetry | Live FG period, target, error, integral, output, ADC values, state |
| Live tuning | Adjust Kp, Ki, target, and calibration values |
| Configuration save/load | Flash-backed settings with validation |
| Firmware update | DFU or equivalent service process |
| Diagnostics | Boot status, fault reporting, power state, USB state |
| Manufacturing / bring-up | Board identification and test commands |

### 13.3 USB-C PD / Power Role

USB-C PD is now part of project scope. The exact implementation remains open.

Required decisions:

| Decision | Options |
|---|---|
| PD implementation | Native STM32 UCPD / external PD controller / staged hybrid |
| Power role | Sink only / service-only USB plus separate power / dual-path |
| Negotiated voltage | Pending power architecture |
| VBUS use | MCU only / full module / motor rail source |
| Failure behavior | Safe no-run / degraded service mode / battery-only |
| Firmware responsibility | Full PD stack / external-controller monitor / none |

### 13.4 Electrical Requirements

- USB D+/D− must be routed as a controlled, short, protected pair appropriate for full-speed USB.
- USB ESD protection is required.
- USB shield termination must be deliberate, not accidental.
- USB ground must not inject objectionable noise into audio, FG, or ADC references.
- USB attach/detach must not disturb capstan servo operation.
- USB telemetry and command handling must not interfere with the servo ISR.
- If native UCPD is used, PD interrupts and firmware must be isolated from real-time servo timing requirements.
- If an external PD controller is used, its default power behavior must be safe without MCU intervention.

### 13.5 Open Questions

- Is the selected STM32G0C1KCU6 package pinout sufficient for servo, ADC, PWM, USB FS, UCPD, BOOT0, and SWD simultaneously? **Resolved: yes; see `docs/stm32g0c1-pin-allocation.md`.**
- Should Rev A use native UCPD or an external PD controller?
- Should USB-C power be required for normal operation, or should battery/barrel operation remain independent?
- Should connecting USB for diagnostics while the machine is otherwise powered be supported?
- How should USB shield connect to WM-D6C chassis/ground?
- Can USB service be exposed without modifying the case beyond acceptable limits?

---

## 14. Grounding and Noise

### 14.1 Signal Name

`GND`

### 14.2 Function

Ground is not just a return conductor. It is the reference for FG measurement, ADC readings, PWM output, USB signaling, PD behavior, power conversion, and motor noise behavior.

### 14.3 Required Bench Checks

- Identify Sony main-board ground points near IC601.
- Identify motor-current return paths.
- Identify audio-path ground sensitivity.
- Measure ground noise during motor startup and steady play.
- Measure USB-connected ground behavior.
- Determine whether DSR-1 should use separate analog/digital/motor/USB return routing joined at one point.

### 14.4 Safety Rules

- Do not route motor current through MCU analog reference paths.
- Do not allow USB ground to inject noise into sensitive audio or servo references without review.
- Avoid long high-impedance ADC wiring.
- Place FG and motor-control returns intentionally.
- Treat USB shield and signal ground separately until the chassis/EMI strategy is selected.

---

## 15. MCU-Side Electrical Constraints

The STM32G0C1KCU6 interface must remain within datasheet limits.

### 15.1 ADC Inputs

Affected signals:

- `RV601_WIPER`
- `RV602_WIPER`
- `RV603_WIPER`
- Optional rail-sense inputs, if added.

Rules:

- ADC input voltage must remain within safe limits for the selected MCU supply.
- Add resistor dividers, series resistors, clamps, or buffers if Sony wipers exceed safe MCU range.
- High-impedance sources require appropriate sampling-time configuration or buffering.
- Analog inputs should include test pads for validation.

### 15.2 Digital Inputs

Affected signals:

- `FG_IN`
- `S601_SPEED_TUNE`
- Any motor-enable or state-detect signal added later.
- USB-C / PD status signals if an external controller is used.

Rules:

- Confirm whether selected STM32 pins are 5 V tolerant before using them with any non-3.3 V signal.
- Add protection if voltage can exceed MCU supply.
- Use defined pull states.
- Use hysteresis or comparator conditioning if edges are slow or noisy.

### 15.3 PWM Output

Affected signals:

- `MOTOR_CTRL`
- Optional filtered PWM output.

Rules:

- PA4/DAC1 direct drive is not used for motor drive.
- PWM output must be filtered and shielded from audio-sensitive paths.
- Output stage must have a known safe state during reset and boot.

### 15.4 USB / UCPD Pins

Affected signals:

- `USB_DP`
- `USB_DM`
- `USB_CC1`
- `USB_CC2`
- `VBUS`

Rules:

- Verify all USB and UCPD pins against the exact selected STM32G0C1KCU6 package.
- Do not assume all family features are available on the chosen package pins.
- USB and UCPD routing must be reflected in the PCB constraints.
- USB service must not consume pins required for safe servo operation unless the pinout decision is explicit.

### 15.5 Clock / Timebase

The firmware can store a target period in flash, but the physical accuracy of that period depends on the timer clock.

Rules:

- Do not claim final speed accuracy until the timebase strategy is decided and verified.
- Internal oscillator operation is acceptable for firmware development and simulation.
- Final hardware must either use a proven timing reference, calibration strategy, or measured evidence that the chosen clock meets project requirements.
- Any external oscillator or retained Sony reference must be reflected in the interface and schematic.
- USB clocking requirements and servo timebase requirements must be reviewed together.

---

## 16. Required Measurement Log Format

Each measurement session should produce a log file under:

```text
docs/measurements/
```

Suggested filename format:

```text
wm-d6c-serial-72795-measurement-log-YYYY-MM-DD.md
```

Each log should include:

| Field | Required |
|---|---|
| Machine model | Yes |
| Serial number | Yes |
| Board photos | Yes |
| Board revision, if known | Yes |
| Service-manual reference used | Yes |
| Test equipment | Yes |
| Power source | Yes |
| USB connection state | If applicable |
| Tape/test fixture used | If applicable |
| Probe grounding method | Yes |
| Measurement location | Yes |
| Raw readings | Yes |
| Interpretation | Yes |
| Open questions | Yes |

Measurements should include raw numbers, not only conclusions.

---

## 17. Rev A Interface Acceptance Criteria

The DSR-1 Rev A interface is not accepted until all items below are complete.

| Requirement | Status |
|---|---|
| Sony-side connection points identified | Pending |
| Board revision documented | Pending |
| FG waveform measured | Pending |
| FG conditioning selected | Pending |
| Motor-control voltage range measured | Pending |
| Motor output stage selected | Pending |
| RV601/RV602/RV603 voltage ranges measured | Pending |
| S601 logic measured | Pending |
| Power rails measured | Pending |
| Power architecture selected | Pending |
| USB-C connector role selected | Pending |
| Native UCPD vs external PD controller decided | Pending |
| USB data/service behavior specified | Pending |
| USB ESD/shield strategy selected | Pending |
| Grounding strategy selected | Pending |
| MCU pinout checked against exact package | Pending |
| Timebase strategy selected | Pending |
| Schematic updated from measurements | Pending |
| ERC passed | Pending |
| Bench simulation passed | Pending |
| Physical Rev A board tested | Pending |
| USB enumeration tested | Pending |
| USB telemetry tested | Pending |
| Firmware update path tested | Pending |
| PD / power negotiation tested, if implemented | Pending |
| Real transport validation passed | Pending |

---

## 18. Open Engineering Questions

1. ~~Which exact servo-circuit revision is present in serial-numbered unit 72795?~~ **Resolved: CX20084 former-type board, observed PCB marking C11-494-12.**
2. What is the actual FG901 waveform at correct tape speed?
3. What is the actual Q601 / motor-control operating voltage?
4. ~~Can the STM32 DAC safely drive the motor-control point?~~ **Resolved: No. Direct DAC drive is not used; PWM + NPN level-shift is the committed topology.**
5. Are RV601/RV602/RV603 wipers safe for direct ADC input?
6. What is the actual logic behavior of S601?
7. What power rails must DSR-1 generate versus merely sense?
8. Should USB-C provide both service data and operating power?
9. Should PD be implemented with STM32 native UCPD or an external controller?
10. What is the safe behavior when USB is connected but the Walkman is off?
11. What is the safe behavior when external power is present but USB data is disconnected?
12. Is the STM32 internal oscillator acceptable after calibration, or is an external timebase required?
13. What original Sony components must be removed, retained, or isolated?
14. How should USB shield/chassis/ground be handled?
15. What case modification, if any, is acceptable for USB-C access?

---

## 19. Design Rule

No DSR-1 schematic node that connects to the Sony WM-D6C or to the USB-C external world may be finalized without one of the following:

1. A service-manual citation and matching schematic location.
2. A datasheet-backed electrical requirement.
3. A bench measurement from a physical unit.
4. A clearly marked assumption with a required validation step.

Assumptions are allowed during design. They are not allowed to become Rev A hardware facts without measurement.

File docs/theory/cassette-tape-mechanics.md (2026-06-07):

# Cassette Tape Mechanics — The WM-D6C Transport

## Purpose of This Document

The DSR-1 Servo Control Board's entire purpose is to maintain a precise tape speed. Understanding
what "precise tape speed" means mechanically — how the WM-D6C's transport achieves
it, what each component contributes, and how the components degrade with age —
provides the foundation for understanding what the servo system is controlling and
why the mechanical service is inseparable from the electronic repair.

This document covers only the WM-D6C's specific transport design and the failure
modes relevant to this project. It is not a general compact cassette primer.

---

## 1. The Fundamental Standard: 4.75 cm/s

The international standard for compact cassette playback speed is 4.75 cm/s — the
tape must move past the playback head at exactly 4.75 centimetres per second. This
is defined by IEC 60094-1 and has been universal since Philips introduced the
compact cassette format in 1963.

The consequences of deviating from 4.75 cm/s are directly audible. Tape speed
determines pitch — a tape playing back at 5% over speed reproduces music at
approximately a semitone too high. A trained ear detects speed errors of 0.5% or
less. The WM-D6C's specification of 0.05% wow and flutter means instantaneous speed
variations are so small they are inaudible under any normal conditions.

For a field recording device used by broadcast professionals — the WM-D6C's intended
application — speed accuracy was critical. A journalist recording an interview needed
the playback to match the original recording precisely, regardless of battery charge
level, operating temperature, or tape reel weight. This is why the WM-D6C has a
closed-loop servo system rather than the simple open-loop motor drive used in
consumer Walkmans.

---

## 2. The WM-D6C Capstan Drive System

### 2.1 The Capstan Shaft

The capstan is a precision-ground stainless steel shaft, approximately 2mm in
diameter, mounted vertically through the transport mechanism chassis. In playback
mode, the tape passes between the capstan shaft and the pinch roller. The tape
speed is determined entirely by the surface speed of the capstan shaft — equal to
the shaft's rotational speed multiplied by its circumference (π × diameter =
approximately 6.28mm per revolution).

At 4.75 cm/s tape speed and a 2mm capstan diameter:

```
Shaft rotational speed = tape speed / circumference
                       = 47.5 mm/s / 6.28 mm/rev
                       = 7.56 rev/s = 454 RPM
```

This is the capstan shaft's target rotational speed during playback. The servo
system's job is to maintain this speed regardless of perturbations.

### 2.2 The Flywheel

The flywheel is a precision-machined metal disc of significant mass (typically
10-15 grams in the WM-D6C) mounted concentrically on the capstan shaft. Its
function is mechanical low-pass filtering: the flywheel's rotational inertia resists
changes in rotational speed, smoothing out the small, rapid speed variations that
the capstan motor inevitably produces.

The flywheel's effectiveness is characterised by its moment of inertia J. For a
flat disc: J = ½mr² where m is the mass and r is the radius. The WM-D6C flywheel,
with a mass of approximately 12g and a radius of approximately 8mm, has:

```
J = ½ × 0.012 × (0.008)² = 3.84 × 10⁻⁷ kg·m²
```

The time constant with which the flywheel resists speed changes from a given
disturbing torque τ is J/τ. For a small disturbance torque of 1 mN·m (roughly
the variation in motor torque from brush commutation):

```
τ_flywheel = J / τ = 3.84×10⁻⁷ / 0.001 = 0.384ms
```

At 454 RPM and 7.56 Hz rotation rate, the angular variation from a 1 mN·m torque
pulse lasting 1ms is:

```
Δω = τ × Δt / J = 0.001 × 0.001 / 3.84×10⁻⁷ = 2.6 rad/s
Δω/ω = 2.6 / (2π × 7.56) = 5.5%
```

Without the flywheel, motor brush commutation would produce 5.5% instantaneous
speed variation — clearly audible. The flywheel's inertia, by integrating this torque
pulse over time rather than converting it directly to velocity, reduces the resulting
speed variation to a level measurable only with precision instruments.

The servo system provides the outer correction loop that corrects for lower-frequency
speed errors (temperature drift, battery discharge, tape tension variation). The
flywheel provides the inner mechanical filter that attenuates high-frequency
disturbances that the servo loop is too slow to correct.

**Flywheel condition significance for this project**: The flywheel bearing (the
sleeve bearing in which the capstan shaft rotates) requires lubrication to operate
smoothly. In a 35-year-old machine, this lubrication has either dried out or
become a sticky gum. Bearing friction adds a load torque to the capstan shaft.
The servo loop can compensate for a steady friction load (the integral term
eliminates the steady-state error), but excessive friction increases the motor's
steady-state operating point, reduces the servo's corrective range in one direction,
and in extreme cases causes the motor to stall. Lubrication is not optional — it is
a prerequisite for correct servo operation.

### 2.3 The Capstan Belt

The capstan motor M901 does not drive the capstan shaft directly. Power is
transmitted from the motor pulley to the flywheel via a rubber drive belt — typically
a flat or round cross-section rubber belt of a specific length and tension.

The belt's role in tape speed accuracy is critical:

**Speed ratio**: The capstan shaft speed relative to the motor speed is determined
by the ratio of the motor pulley diameter to the flywheel diameter. For the WM-D6C,
this ratio is fixed at the motor's nominal operating speed — the servo system is
calibrated to lock the capstan shaft to the correct rotational speed.

**Belt slip**: A new belt in good condition transmits power with negligible slip.
An aged belt that has lost elasticity, hardened, or become glazed introduces slip
between the motor pulley and the flywheel. Belt slip means the motor can spin at
the servo's target speed while the flywheel (and therefore the capstan shaft and
tape) moves slower. The FG sensor is on the motor shaft, not the capstan shaft —
the servo locks the motor speed, which is no longer the same as the capstan speed.
Result: consistent speed error that cannot be corrected by servo tuning.

**Belt stretching**: A stretched belt has reduced tension. This increases the
tendency to slip under load and changes the effective drive ratio slightly. A
significantly stretched belt causes the capstan to run at the wrong speed even at
correct motor speed.

**Belt degradation modes in the WM-D6C**: The original belt in a 35-year-old
machine is almost certainly past its service life. The three failure modes in order
of likelihood are: hardening and glazing (reduced grip, increased slip); stretching
(reduced tension, changed drive ratio); and complete breakdown (belt becomes
crumbly, sticky, or breaks). The FixYourAudio rubber kit addresses all of these
with a belt manufactured to the correct dimensions for the WM-D6C.

### 2.4 The FG Sensor and Slotted Disc

The FG901 GP2S22AB optical sensor measures the rotational speed of the motor shaft,
not the capstan shaft. This is a critical design detail: the sensor is before the
belt in the power transmission path. If the belt is slipping, the sensor reports
the motor speed correctly but the capstan shaft is moving slower.

The slotted disc is a thin metal disc with precision-cut slots around its
circumference, mounted on the motor shaft. The FG901 sensor detects each slot
passage as the motor rotates. The relationship between the number of slots and the
FG pulse rate determines the servo's speed reference:

```
FG pulse rate = motor RPM × (slots per revolution) / 60
```

For the WM-D6C, the exact number of slots must be determined from the FG pulse rate
at correct tape speed (measured with a calibrated test tape). This is the
FG_TARGET_HZ value in `config.h`.

**FG disc contamination**: The FG disc is physically adjacent to the capstan belt.
As the belt ages and degrades, it sheds rubber particles and leaves a greasy residue
on every surface it contacts. This contamination can partially obstruct the FG901's
optical path, reducing the pulse amplitude. If the pulse amplitude drops below the
threshold where it can be detected through the level-shifting network, the servo
loses its speed reference and the motor runs open-loop — precisely the symptom of
a failed CX20084. FG disc cleaning is mandatory before diagnosing any electronic
fault.

---

## 3. The Pinch Roller

### 3.1 Function

The pinch roller is a rubber-coated wheel mounted on a spring-loaded pivot. In
playback mode, the transport mechanism presses the pinch roller against the capstan
shaft, with the tape sandwiched between them. The tape is driven forward by the
friction between the capstan shaft surface and the pinch roller rubber — the
capstan pushes the tape, the pinch roller provides a compliant backing surface.

The pinch roller does not determine tape speed — that is the capstan's job. The
pinch roller's function is to maintain consistent contact pressure between the tape
and the capstan shaft so that the capstan's surface speed is reliably transferred
to the tape without slip. Insufficient contact pressure allows the tape to slip
against the capstan, producing apparent speed variation. Excessive pressure creates
high tape tension, increased tape wear, and additional load on the capstan bearing.

The WM-D6C's cassette-holding spring is adjusted to provide 130-260g (4.59-9.17 oz)
of force pressing the cassette (and with it the pinch roller) against the capstan
shaft, as specified in the service manual. This preload is designed around the
mechanical properties of new rubber on a smooth shaft.

### 3.2 Pinch Roller Degradation and Its Effects

The pinch roller rubber hardens progressively over time through oxidation and
physical set (compression creep). The original rubber in a WM-D6C pinch roller
manufactured in 1990 is now 35 years old. Under normal circumstances it will be
substantially harder than new rubber, often resembling plastic in its hardness.

**Hardened roller — reduced grip**: A hard, smooth pinch roller has reduced
coefficient of friction against the capstan shaft. Under load, the tape may slip
rather than being driven at capstan surface speed. This appears as erratic,
inconsistently-fast, or wandering playback speed that the servo loop partially
corrects but cannot eliminate because the slippage is stochastic and load-dependent.

**Hardened roller — changed geometry**: As rubber hardens, it often develops a
concave or convex wear profile from decades of contact with the capstan shaft. This
changes the contact patch geometry, potentially causing the tape to be driven at
different speeds across its width — one edge moving faster than the other — which
produces azimuth-like treble loss from poor head contact uniformity.

**Glazed roller**: A pinch roller that has been in contact with the capstan shaft
without use for extended periods (e.g., a machine in storage with a cassette
loaded and in play mode) develops a glazed contact surface with extremely low
friction. A glazed roller feels smooth and almost polished. It will not grip the
tape adequately under any conditions and must be replaced.

**The micrometer measurement**: Before installing the replacement pinch roller,
measure the original and the replacement as described in the installation notes:
outer diameter, face width, and shaft bore. The diameter is the most critical
dimension — a roller that is even 0.5mm smaller in diameter reduces the tape-to-
capstan contact pressure by changing the geometric relationship, potentially
allowing tape flutter. The replacement from a specialist supplier for the WM-D6C
should be dimensionally correct, but verification eliminates any uncertainty.

---

## 4. The Reel Drive System and Tape Tension

### 4.1 Why Tape Tension Matters for Speed

The capstan determines tape speed. But the tape must also be kept taut — if the
take-up reel doesn't pull the tape away from the capstan fast enough, the tape will
accumulate between the capstan and the reel, eventually jamming. If the supply reel
doesn't provide enough back-tension, the tape will be insufficiently taut at the
head, degrading playback quality.

The reel drive system provides:
- **Take-up torque**: A gentle forward pull on the tape after the capstan, keeping
  it wound onto the take-up reel
- **Supply back-tension**: A light braking force on the supply reel, keeping the
  tape taut between the supply reel and the head block

Both of these forces must be correctly balanced. If the take-up torque is too high,
the tape is pulled against the capstan with extra force, increasing the load torque
the servo must overcome. If the back-tension is too low or too high, the tape does
not lie flat against the playback head.
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

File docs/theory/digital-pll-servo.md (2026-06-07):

# The DSR-1 Digital PLL Servo Loop

## Purpose of This Document

This document explains how the DSR-1 Servo Control Board's digital servo loop works — the period
measurement, the PI control algorithm, the fixed-point arithmetic, and the motor
drive output. It is written for someone who understands the original analog servo
(see [original-servo-circuit.md](original-servo-circuit.md)) and wants to understand
how the digital replacement achieves the same function, and why it does so more
accurately.

---

## 1. The Same Goal, a Different Approach
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

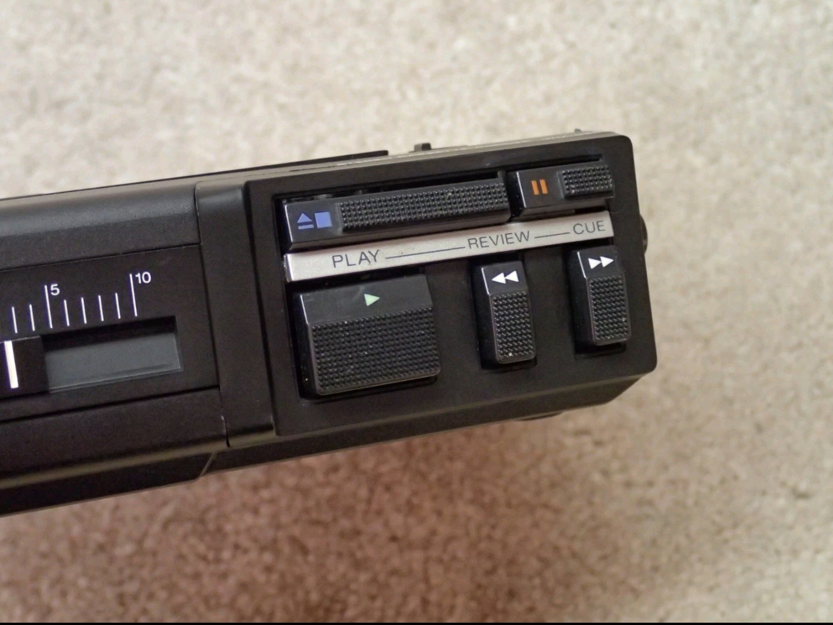
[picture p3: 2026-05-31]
docs/photos/overview/17-tape-control-buttons.jpg

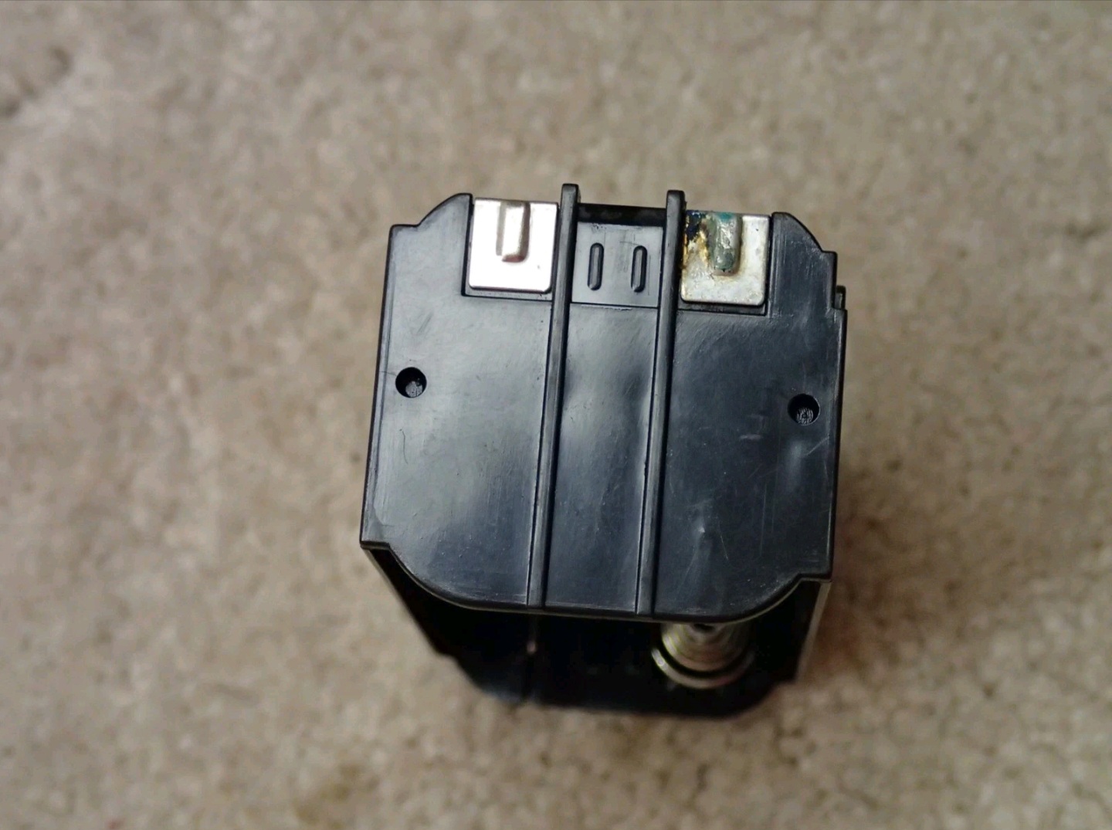
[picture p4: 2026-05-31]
docs/photos/overview/15-battery-holder-bottom.jpg

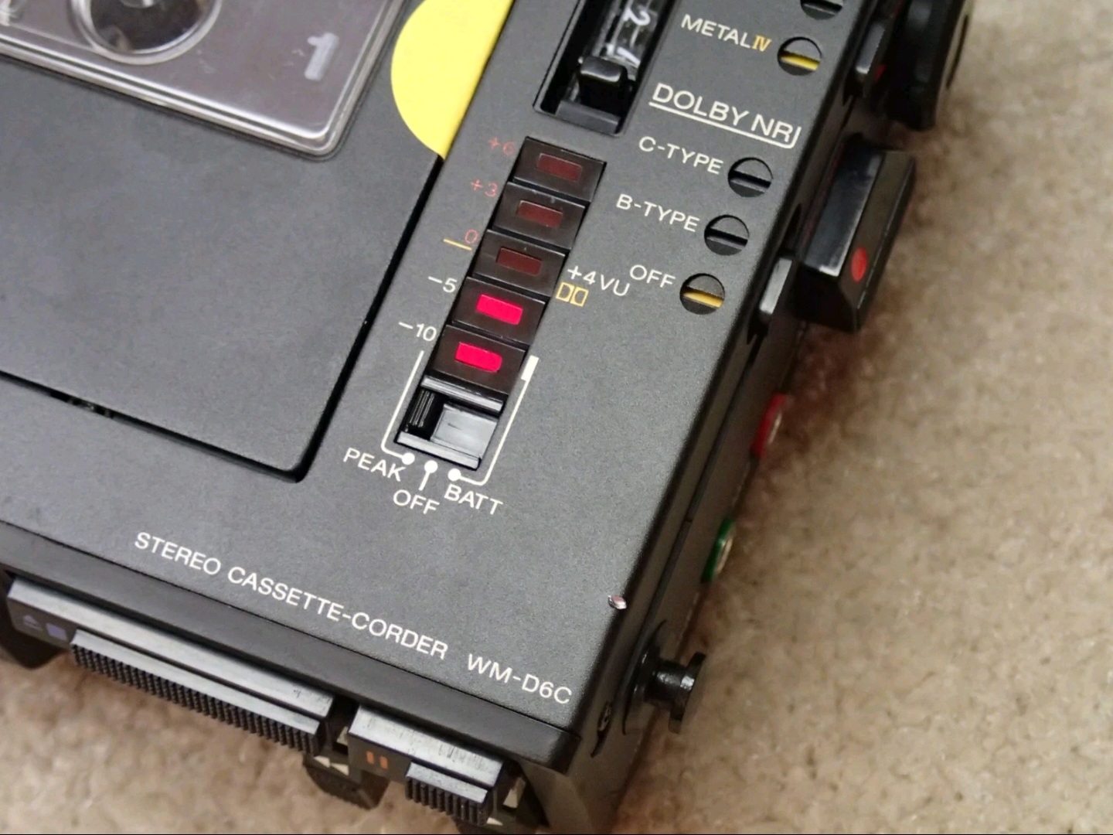
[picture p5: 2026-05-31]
docs/photos/overview/04-vu-meter-closeup.jpg

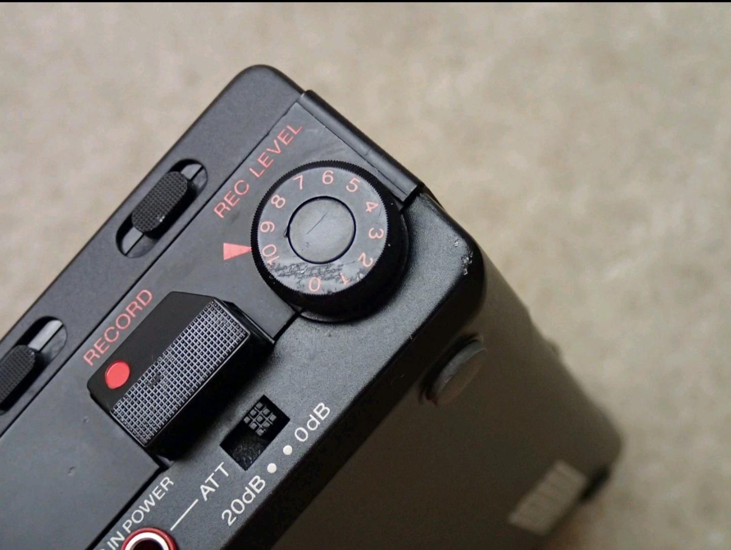
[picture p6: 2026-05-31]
docs/photos/overview/20-record-controls-closeup.jpg

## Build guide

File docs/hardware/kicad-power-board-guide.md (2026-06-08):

# WM-D6C Power Board — KiCad 10 Schematic Guide

**Project:** `hardware/kicad/Power-Board/wm-d6c-power-board/`  
**Tool:** KiCad 10.x  
**Scope:** Power Board schematic only; one flat schematic sheet  
**Rev A target:** Battery-integrated WM-D6C using three parallel LiPo cells

This guide defines the locked Power Board architecture for the DSR-1 project.

The Power Board replaces the original four-AA holder, the corroded battery contacts,
and the original barrel-jack power path. It receives only USB-C 5 V power and ground,
charges the internal 1S3P LiPo pack, and generates regulated Sony `B+1` at 6.0 V.

The Power Board does **not** own USB data, USB-C CC handling, the STM32, the LED battery
monitor, `B+3`, or `+3V3`.

---

## 1. Locked Board Boundary

### Power Board owns

| Function | Responsibility |
|---|---|
| USB-C power input | `VBUS_5V` and GND only |
| Charging | BQ24074-class power-path charger |
| Energy storage | Three 803040 LiPo cells in parallel, treated as one 1S3P pack |
| Pack protection | DW01A/FS8205-class single-cell protection topology or selected equivalent |
| Main rail generation | TPS63070 buck-boost, `V_SYS` to regulated `B+1` = 6.0 V |
| Machine power injection | `B+1` and GND to the original battery-terminal PCB pads |
| Telemetry export | ADC-safe battery sense and charger status to the Servo Board |

### Power Board does not own

| Excluded function | Owner |
|---|---|
| USB D+ / D− | Servo Board |
| USB-C CC1 / CC2 | Servo Board |
| USB CDC, DFU, tuning, firmware update, data debugging | Servo Board |
| STM32 | Servo Board |
| Five-segment LED battery monitor | Servo Board |
| `B+3` generation | Servo Board |
| `+3V3` generation | Servo Board |
| Barrel-jack input | Removed |
| USB-C PD / 9 V negotiation | Not used |

---

## 2. System Power Flow

```text
USB-C VBUS_5V + GND
    -> BQ24074 power-path charger
    -> V_SYS
    -> TPS63070 buck-boost
    -> B+1 = regulated 6.0 V
    -> original WM-D6C battery-positive and battery-negative PCB pads
    -> S901 / original WM-D6C B+1 distribution
    -> original CP304 connector
    -> Servo Board receives B+1 and GND
```

The original battery holder and corroded contacts are removed. The PCB pads formerly
fed by those contacts become the permanent B+1 and GND injection points.

`B+1` is Sony's 6 V rail. Do not create a second independent `+6V` rail.

---

## 3. Current KiCad Cleanup

The current Power Board project is a migration skeleton. Before adding the final
battery architecture:

1. Remove or DNP IP2721 and all `9V_PD` circuitry.
2. Remove or DNP the barrel-jack input and polarity-correction blocks.
3. Remove AP63203.
4. Remove MT3608 and all `B+3` generation from this project.
5. Remove MCP1700 and all `+3V3` generation from this project.
6. Remove USB D+/D− and CC1/CC2 circuitry from this project.
7. Retain or place the BQ24074, three cell connectors, protection circuit, TPS63070,
   machine-output pads, telemetry connector, and test points.
8. Run ERC after each major block is completed.

The Power Board shall remain one flat schematic sheet.

---

## 4. Suggested Sheet Layout

```text
+ USB-C Power +----+ Charger / Pack +----+ B+1 Converter +----+ Machine Output +----+ Telemetry +
| 5 V and GND |    | BQ24074        |    | TPS63070      |    | battery pads   |    | to Servo  |
| only         |    | 1S3P + protect |    | 6.0 V         |    | B+1 and GND    |    | status     |
+--------------+----+----------------+----+---------------+----+----------------+----+------------+
```

Visual zones have no electrical meaning. Use ordinary same-sheet net labels.

---

## 5. Zone A — USB-C Power Input

The system USB-C receptacle is shared between the boards, but the Power Board receives
only the power pair.

| USB-C item | Power Board connection |
|---|---|
| VBUS pins | `VBUS_5V` |
| GND pins | GND |
| D+ / D− | No Power Board connection |
| CC1 / CC2 | No Power Board connection |
| SBU1 / SBU2 | No connection |
| Shield | Explicit EMC/chassis strategy |

### Rules

- Rev A uses default USB-C 5 V only.
- Do not negotiate or accept a 9 V PD contract.
- Do not place CC pull-downs on the Power Board.
- Do not place USB data ESD devices on the Power Board.
- Add VBUS transient protection and charger-input capacitance near the physical
  VBUS entry point.
- Add `TP_VBUS`.
- Verify that no battery or system rail can backfeed `VBUS_5V`.

### Source-current policy

CC current advertisement is handled on the Servo Board. The Power Board therefore
must be designed around a documented external USB-C supply requirement.

The programmed charger input limit must not exceed the current available from that
documented source. Deck operation takes priority over charging.

---

## 6. Zone B — Charger and Power Path

### U_CHG — BQ24074-class charger

Follow the selected device datasheet reference circuit. Do not add an external
VBUS-to-system Schottky load-sharing diode or a separate battery load-sharing P-FET
that bypasses the charger's internal power path.

| Function | Connection |
|---|---|
| IN | `VBUS_5V` |
| OUT | `V_SYS` |
| BAT | Protected pack positive domain |
| VSS / exposed pad | GND and thermal copper |
| CHG | `CHG_STAT_N` to Servo Board |
| PGOOD | `PGOOD_N` to Servo Board |
| ISET | Select using datasheet formula |
| ILIM | Select using datasheet formula and allowed range |
| TS | Real NTC or datasheet-valid fixed configuration |
| CE / EN pins | Defined state; never floating |
| TMR / ITERM | Deliberately configured |
| IN / OUT / BAT capacitors | Values and placement per datasheet |

### Mandatory corrections

- Do not use the earlier `800 ohm = 2 A` ILIM claim.
- Do not assume the charger can accept a 2 A programmed input limit.
- Pull `CHG_STAT_N` and `PGOOD_N` up to Servo Board `+3V3`, not to VBUS.
- Use enough copper for charger thermal dissipation.
- Select charge current to support simultaneous deck operation and charging without
  collapsing the USB source or overheating the charger.

---

## 7. Zone C — Three-Cell 1S3P Pack

Three 803040 LiPo cells are connected in parallel.

```text
Cell 1 + ----+
Cell 2 + ----+---- CELL_POS_RAW
Cell 3 + ----+

Cell 1 - ----+
Cell 2 - ----+---- CELL_NEG_RAW
Cell 3 - ----+
```

This is one logical 1S3P pack:

- nominal voltage: approximately 3.7 V
- full-charge voltage: 4.2 V
- three times the capacity of one cell, subject to actual cell rating

### Assembly rules

- Voltage-match the cells before first parallel connection.
- Use serviceable, polarized connectors or clearly documented solder pads.
- Do not mix cells of different chemistry, age, capacity, or condition.
- Leave mechanical allowance for cell swelling.
- Document cell orientation and polarity on the silkscreen.

---

## 8. Zone D — Pack Protection

Use the exact reference circuit for the final selected DW01A/FS8205-class parts.

Recommended net naming:

| Net | Meaning |
|---|---|
| `CELL_POS_RAW` | Raw parallel-cell positive |
| `CELL_NEG_RAW` | Raw parallel-cell negative before protection FETs |
| `VBAT_PROT` | Protected battery positive / charger BAT domain |
| `PACK_NEG_PROT` | Protected negative after the FETs |
| GND | System ground on the protected side |

### Critical rules

- Do not connect `CELL_NEG_RAW` directly to system GND.
- The protection FETs must remain in the only current path between raw cell negative
  and protected system ground.
- Follow the final protection IC's recommended FET orientation exactly.
- Add test points on raw cell voltage and protected pack output.
- If the selected cells include individual protection boards, document the interaction
  with the Power Board protection before deciding whether both are populated.

---

## 9. Zone E — B+1 Regulator

### U_B1 — TPS63070 buck-boost

The TPS63070 generates regulated Sony `B+1` from `V_SYS`.

| Function | Connection |
|---|---|
| VIN pins | `V_SYS` |
| VOUT pins | `B+1` |
| FB | Feedback-divider midpoint |
| L1 / L2 | Inductor between the two switch pins |
| EN | Defined enable state |
| PS/SYNC | Defined operating mode |
| VSEL / FB2 | Deliberately configured for the chosen single-output mode |
| VAUX | Local bypass capacitor; not a general-purpose supply |
| PG | Use or mark correctly; pull up if used |
| GND / exposed pad | Low-impedance ground and thermal copper |

Target feedback divider:

```text
B+1 = 0.8 V * (1 + 649 k / 100 k)
     = approximately 6.0 V
```

### Design rules

- Use datasheet-recommended input and output capacitance.
- Do not treat one 10 uF output capacitor as a sufficient default.
- Account for ceramic-capacitor DC-bias derating.
- Select the inductor from calculated peak current at minimum pack voltage, maximum
  deck load, startup surge, and expected efficiency.
- Keep the high-current switching loop compact.
- Keep the switch node away from battery sense and telemetry traces.
- Add `TP_SYS`, `TP_B1`, and GND test points.
- Place a PWR_FLAG only at the real B+1 source.

---

## 10. Machine Power Output

The Power Board connects permanently to the main-board pads formerly connected to
the battery holder.

| Net | Direction | Destination |
|---|---|---|
| `B+1` | Power Board to WM-D6C | Former battery-positive PCB pad |
| GND | Shared | Former battery-negative PCB pad |

Use mechanically robust wire attachment, strain relief, and adequate conductor gauge.

The original battery holder, spring contacts, and corroded terminal hardware are not
retained.

S901 remains the WM-D6C master power switch.

---

## 11. Servo Board Telemetry Connector

This connector carries only low-current telemetry and control signals. It does not
carry USB data, CC signals, B+1, B+3, or +3V3.

| Pin/net | Direction | Purpose |
|---|---|---|
| GND | Shared | Telemetry reference |
| `VBAT_SENSE` | Power Board to Servo Board | ADC-safe scaled battery voltage |
| `VBAT_SENSE_EN` | Servo Board to Power Board | Optional divider enable |
| `CHG_STAT_N` | Power Board to Servo Board | Active-low charger status |
| `PGOOD_N` | Power Board to Servo Board | Active-low valid-input status |

### Battery-sense implementation

Preferred arrangement:

```text
raw pack voltage
    -> high-value divider on Power Board
    -> optional high-side or properly isolated enable switch
    -> VBAT_SENSE, always ADC-safe
    -> Servo Board PB0 / ADC_IN8
```

Rules:

- `VBAT_SENSE` must never mean raw 4.2 V pack voltage.
- Do not use the same net name on both sides of the upper divider resistor.
- Do not use a low-side switching arrangement that lets the disabled ADC node float
  toward raw battery voltage.
- Place the ADC filter capacitor on the divided `VBAT_SENSE` node.

---

## 12. Required Test Points

| Test point | Net |
|---|---|
| TP_VBUS | `VBUS_5V` |
| TP_SYS | `V_SYS` |
| TP_CELL_POS | `CELL_POS_RAW` |
| TP_CELL_NEG | `CELL_NEG_RAW` |
| TP_VBAT | Protected battery domain |
| TP_B1 | `B+1` |
| TP_CHG | `CHG_STAT_N` |
| TP_PGOOD | `PGOOD_N` |
| TP_GND | GND |

---

## 13. ERC and Review Targets

Before layout:

- No `9V_PD`, IP2721, barrel-jack, B+3, +3V3, USB data, or CC circuitry remains.
- `VBUS_5V` cannot be backfed.
- All charger pins and required capacitors are handled intentionally.
- Raw cell negative cannot bypass the protection FETs.
- Battery-sense output is always STM32-safe.
- TPS63070 L1/L2, VAUX, PS/SYNC, VSEL, FB2, PG, EN, FB, grounds, and exposed pad are
  all handled intentionally.
- TPS63070 output capacitance and inductor current rating are justified.
- `B+1` and GND are the only machine power-injection nets.
- ERC has no unexplained errors.

---

## 14. Standalone Bring-Up Order

1. Continuity and polarity checks with no cells and no USB.
2. Verify no raw-negative-to-GND protection bypass.
3. Apply current-limited USB 5 V with no cells.
4. Verify charger input behavior and absence of VBUS backfeed.
5. Connect a protected test cell or current-limited battery simulator.
6. Verify charger state transitions and thermal behavior.
7. Verify `V_SYS`.
8. Bring up TPS63070 into a dummy load.
9. Verify 6.0 V B+1 across expected load and startup transients.
10. Verify USB removal hands the load to the pack.
11. Verify telemetry outputs and battery-sense scaling.
12. Only then connect the Power Board to the WM-D6C.

---

## Commit Template

```text
git add hardware/kicad/Power-Board/wm-d6c-power-board \
        docs/hardware/kicad-power-board-guide.md
git commit -m "Revise Power Board guide for locked Rev A architecture"
```

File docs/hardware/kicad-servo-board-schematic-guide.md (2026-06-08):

# DSR-1 Servo Control Board — KiCad 10 Schematic Guide

**Project:** `hardware/kicad/DSR-1/`  
**Tool:** KiCad 10.x  
**Scope:** Servo Control Board schematic only; one flat D-size sheet  
**Rev A target:** Sony WM-D6C serial 72795, PCB `C11-494-12`, former-type CX20084 circuit

This guide reflects the locked Rev A architecture.

The Servo Board replaces the original CP304 DC-DC converter and the failed CX20084
servo function. It receives Sony `B+1` at 6.0 V and GND from the original CP304
connector, generates local `+3V3` and `B+3`, handles all USB signals except VBUS power
and ground, runs the digital servo, and provides the mandatory five-segment battery
monitor.

The separate Power Board receives USB-C 5 V and ground, charges the 1S3P LiPo pack,
and injects regulated `B+1` into the former battery-terminal PCB pads.

---

## 1. Confirmed Compatibility

The target unit is:

| Item | Confirmed value |
|---|---|
| Model | Sony WM-D6C |
| Serial | 72795 |
| PCB marking | `C11-494-12` |
| Manual family | Former type / Ver. 1.0 |
| Servo IC | CX20084 |
| Motor-control family | Single-Q601 former-type architecture |
| Rev A applicability | Yes |

The v1.1 manual identifies the corresponding `1-611-494-12` board family as former
type. The later CX-069A/Q601–Q605 circuit is out of scope for Rev A.

Use the original service manual `fb4872.pdf` as the governing Sony electrical
reference. Use the v1.1 manual to identify the incompatible later circuit family.

The service manual establishes Q601 as a PNP control path. The exact SMD package,
marking, base voltage, and current on this physical unit still require bench
confirmation before final resistor values are frozen.

---

## 2. Locked Board Boundary

### Servo Board owns

| Function | Responsibility |
|---|---|
| Sony power input | Receive `B+1` 6 V and GND at the former CP304 connector |
| Motor rail | Generate `B+3` at approximately 10.8 V |
| Logic rail | Generate local `+3V3` |
| Servo controller | STM32G0C1KCU6 and firmware |
| FG input | Conditioning and TIM2 input capture |
| Motor drive | PWM, filter, level shift, Q601-base interface |
| Speed controls | RV601, RV602, RV603, S601 |
| Motor enable | Monitor former IC601 pin-7 network |
| USB signaling | D+, D−, CC1, CC2, ESD, sink termination, USB firmware |
| Programming/recovery | USB DFU/application update plus mandatory SWD |
| Battery monitor | Five LED outputs, S801 BATT-mode input, battery/status telemetry |

### Servo Board does not own

| Excluded function | Owner |
|---|---|
| USB-C 5 V power processing | Power Board |
| LiPo charging | Power Board |
| LiPo protection | Power Board |
| B+1 generation | Power Board |
| Original barrel jack | Removed |
| USB-C PD / 9 V negotiation | Not used |

---

## 3. Current KiCad Cleanup

The committed `DSR-1.kicad_sch` root is already a flat D-size sheet. Do not attempt
to remove hierarchical sheet rectangles that are not present.

Use this migration sequence:

1. Make a branch or backup.
2. Open `DSR-1.kicad_sch` as the working flat schematic.
3. Remove IP2721, barrel-jack, AP63203, charger, battery-protection, and B+1-generation
   blocks from the root.
4. Retain or rebuild the MT3608 B+3 converter.
5. Retain or rebuild the local 3.3 V regulator.
6. Consolidate the STM32, signal conditioning, USB signaling, CP304 interface,
   Sony servo harness, LED interface, telemetry link, and debug header on the root.
7. Use orphaned legacy child schematics only as visual references.
8. Archive or delete legacy child sheets only after confirming no unique circuitry
   remains.
9. Replace hierarchical labels with ordinary same-sheet net labels.
10. Run ERC after each completed zone.

---

## 4. Suggested Flat-Sheet Layout

```text
+ Power Rails +----+ MCU / USB +----+ Signal Conditioning +----+ Sony Interfaces +
| B+1 input   |    | STM32      |    | FG, ADC, motor      |    | CP304, IC601    |
| 3.3 V       |    | USB/CC     |    | enable, clamps      |    | pots, S601      |
| B+3 boost   |    | SWD/reset  |    | battery sense       |    | LED/status      |
+-------------+----+------------+----+---------------------+----+-----------------+
```

Use ordinary net labels for same-sheet connections. Use power symbols for `B+1`,
`B+3`, `+3V3`, and GND.

---

## 5. Zone A — CP304 Replacement Power Interface

The Servo Board occupies the original CP304 function and receives power through the
original CP304 connector or its documented replacement harness.

Required electrical functions:

| Net | Direction | Function |
|---|---|---|
| `B+1` | WM-D6C to Servo Board | Regulated 6.0 V input |
| GND | Shared | Power return |
| `B+3` | Servo Board to WM-D6C | Approximately 10.8 V motor rail |

The exact connector pin numbering and mechanical footprint must be confirmed against
the physical machine and service manual before layout.

### Rules

- `B+1` is already the Sony 6 V rail; do not regenerate it locally.
- Do not place a series diode that blocks B+1 from entering the Servo Board.
- If reverse-current protection is required, use a topology compatible with the
  actual power direction.
- Add test points for B+1, B+3, +3V3, and GND.
- Place a PWR_FLAG at the incoming B+1 connector so ERC recognizes the external source.

---

## 6. Zone B — Local 3.3 V Rail

Generate `+3V3` locally from B+1.

The existing architecture uses an MCP1700-class 3.3 V regulator. Confirm the final
part's current capability against:

- STM32 maximum current
- USB activity
- five LED-control interfaces
- status pull-ups
- signal-conditioning loads
- debug and test loads

Required connections:

```text
B+1 -> regulator VIN
regulator GND -> GND
regulator VOUT -> +3V3
```

Use the final regulator datasheet's required input and output capacitors close to the
pins.

Add:

- `TP_3V3`
- input bulk capacitance as justified
- local decoupling at each load
- a PWR_FLAG at the real +3V3 source

Do not power the Servo Board from the SWD header or USB VBUS.

---

## 7. Zone C — B+3 Motor-Rail Converter

The Servo Board replaces CP304 and generates approximately 10.8 V B+3 from 6.0 V B+1.

### MT3608-class boost topology

```text
B+1 -> inductor -> SW node
                     +-> MT3608 SW
                     +-> Schottky diode anode
Schottky cathode -> B+3
B+3 -> output capacitors -> GND
B+3 -> upper feedback resistor -> FB
FB -> lower feedback resistor -> GND
```

Existing target divider:

```text
R_upper = approximately 169 k
R_lower = 10 k
VOUT = approximately 10.8 V
```

### Rules

- Verify the final converter datasheet and exact part.
- Keep the SW node short.
- Keep switching current away from FG, ADC, USB, and Q601-control traces.
- Select the inductor and diode for startup and motor-current transients.
- Use output capacitance appropriate for the motor supply.
- Add B+3 overvoltage and loaded-startup testing to bring-up.
- Add `TP_B3`.

---

## 8. Zone D — STM32G0C1KCU6

Use `STM32G0C1KCU6` in UFQFPN32.

### Confirmed Rev A pin allocation

| Pin | MCU signal | DSR-1 function |
|---:|---|---|
| 1 | PB9 | Spare / NC |
| 2 | PC14 | NC |
| 3 | PC15 | NC |
| 4 | VDD/VDDA | `+3V3` |
| 5 | VSS/VSSA | GND |
| 6 | PF2-NRST | NRST |
| 7 | PA0 | `FG_IN` / TIM2_CH1 |
| 8 | PA1 | `RV601_WIPER` / ADC_IN1 |
| 9 | PA2 | `RV602_WIPER` / ADC_IN2 |
| 10 | PA3 | `RV603_WIPER` / ADC_IN3 |
| 11 | PA4 | Spare / NC |
| 12 | PA5 | `MOTOR_EN_MON` |
| 13 | PA6 | `MOTOR_PWM` / TIM3_CH1 |
| 14 | PA7 | `SPEED_TUNE_SW` |
| 15 | PB0 | `VBAT_SENSE` / ADC_IN8 |
| 16 | PB1 | `VBAT_SENSE_EN` |
| 17 | PB2 | `BATT_LED1` |
| 18 | PA8 | `CC1` |
| 19 | PA9 | `CC2` |
| 20 | PC6 | `S801_BATT` |
| 21 | PA10 | Spare / NC |
| 22 | PA11 | `USB_DM` |
| 23 | PA12 | `USB_DP` |
| 24 | PA13 | `SWDIO` |
| 25 | PA14-BOOT0 | `SWDCLK` / BOOT0 |
| 26 | PA15 | `BATT_LED2` |
| 27 | PB3 | `BATT_LED3` |
| 28 | PB4 | `BATT_LED4` |
| 29 | PB5 | `BATT_LED5` |
| 30 | PB6 | `DEBUG_TX` |
| 31 | PB7 | `CHG_STAT_N` |
| 32 | PB8 | `PGOOD_N` |
| EP | VSS | GND |

The GP K package has combined VDD/VDDA and VSS/VSSA pins and no separate VDDIO2 pin.

### Decoupling

Place local decoupling from pin 4 to GND:

- 100 nF X5R
- 1 uF X5R
- optional additional analog-noise capacitor only if justified by the final ADC design

Keep the primary 100 nF capacitor closest to the supply pin.

Ground the exposed pad with a via array.

### Reset and boot

NRST:

```text
NRST -> 100 nF -> GND
NRST -> SWD/recovery header
```

BOOT0 / PA14:

```text
PA14-BOOT0 -> 10 k pull-down -> GND
PA14-BOOT0 -> SWDCLK
```

Do not hard-wire PA14 to both 3.3 V and ground.

Provide documented test access if forced bootloader entry is required.

---

## 9. Zone E — USB-C Signaling

The Power Board receives only USB-C 5 V and GND. The Servo Board receives and owns
all remaining USB-C signals:

| Signal | Servo Board function |
|---|---|
| `USB_DP` | STM32 USB D+ |
| `USB_DM` | STM32 USB D− |
| `CC1` | USB-C sink configuration / monitoring |
| `CC2` | USB-C sink configuration / monitoring |
| GND | USB signal reference |

### USB data path

```text
USB-C D+ / D−
    -> ESD protection near connector or Servo Board entry
    -> optional required series components from STM32 reference design
    -> PA12 / PA11
```

Route D+ and D− as a short, tightly coupled differential pair with a continuous
ground reference.

### CC handling

Rev A is a 5 V-only USB-C sink.

The hardware must present valid sink termination before firmware starts. Use one
datasheet-compliant Rd termination on each CC pin unless the final STM32 UCPD
implementation provides an explicitly verified equivalent.

```text
CC1 -> valid Rd / protection -> PA8 as designed
CC2 -> valid Rd / protection -> PA9 as designed
```

No 9 V PD negotiation is used.

### USB functions

USB is mandatory for:

- USB CDC telemetry
- servo tuning
- diagnostic logging
- firmware update
- application communication

USB does not replace SWD for blank-device programming, breakpoint debugging, or
recovery from corrupted firmware.

### Physical interconnect

If the USB-C receptacle is not physically mounted on the Servo Board:

- use a short connector or flex designed for USB 2.0 Full Speed
- route D+ and D− together
- provide adjacent ground reference
- do not use a long unordered wire bundle
- place ESD protection at the connector-side entry whenever practical

The Servo Board is not powered from USB VBUS. Its operating power remains B+1 through
the CP304 connection.

---

## 10. Zone F — FG Input

FG901 is an open-collector optical feedback source pulled up on the Sony circuitry.

The actual target waveform must be measured before final values are frozen.

Recommended placeholder topology:

```text
FG_RAW
    -> upper divider resistor
    -> FG_COND
FG_COND
    -> lower divider resistor -> GND
    -> rail clamp network
    -> small C0G filter if measurement supports it
    -> PA0 / FG_IN
```

Rules:

- Do not connect FG_RAW directly to the STM32.
- Size the divider so normal high level remains below the STM32 input limit without
  relying on continuous clamp conduction.
- Ensure the clamp cannot back-power an unpowered +3V3 rail.
- Select filtering from measured ringing and edge rate.
- Add `TP_FG_RAW` and `TP_FG_IN`.

The existing 10 k / 22 k values remain provisional until measured.

---

## 11. Zone G — Motor-Control Output

The original manual establishes a former-type PNP Q601 control path. Lower base
voltage relative to the B+3-referenced emitter increases motor drive; raising the
base toward the emitter turns Q601 off.

The exact target-unit Q601 package, base voltage, base current, startup behavior, and
safe-off voltage must be measured.

Committed architecture:

```text
PA6 / MOTOR_PWM
    -> PWM filter / base limiting
    -> MMBT3904-class NPN level shifter
    -> Q601_BASE interface
    -> off-board Sony Q601
```

Rules:

- Default reset state must leave Q601 safely off.
- BOOT0, USB attach, firmware update, and MCU reset must not command uncontrolled motor
  drive.
- Do not freeze R7, R8, R9, or filter values before Q601 bench characterization.
- Provide `TP_MOTOR_PWM`, `TP_LEVEL_SHIFT`, and `TP_Q601_BASE`.
- Test the output stage into a dummy load before connecting it to Q601.

---

## 12. Zone H — Motor Enable and Speed Controls

### Motor-enable monitor

The former IC601 pin-7 network is approximately 4.4 V during play and is pulled low
by the Auto-Off circuitry.

Use a divider sized from bench measurements before PA5.

```text
MOTOR_EN_RAW -> divider -> MOTOR_EN_MON -> PA5
```

Add a test point on both sides of the divider.

### RV601, RV602, RV603

Each Sony wiper must be measured for:

- full voltage range
- source impedance
- polarity
- interaction with Speed Tune
- behavior when the Servo Board is unpowered

Use a divider where required. A small series resistor and clamp alone is not an
acceptable final design for a sustained overvoltage.

Map:

| Sony control | STM32 |
|---|---|
| RV601 | PA1 / ADC_IN1 |
| RV602 | PA2 / ADC_IN2 |
| RV603 | PA3 / ADC_IN3 |
| S601 | PA7 / `SPEED_TUNE_SW` |

Add ADC filter capacitors only after determining acceptable source impedance and
sample time.

---

## 13. Zone I — Power Board Telemetry

The Power Board sends only telemetry/control signals to the Servo Board.

| Net | Direction | STM32 |
|---|---|---|
| GND | Shared | Ground reference |
| `VBAT_SENSE` | Power Board to Servo Board | PB0 / ADC_IN8 |
| `VBAT_SENSE_EN` | Servo Board to Power Board | PB1 |
| `CHG_STAT_N` | Power Board to Servo Board | PB7 |
| `PGOOD_N` | Power Board to Servo Board | PB8 |

Rules:

- `VBAT_SENSE` must already be ADC-safe when it reaches the Servo Board.
- Place the final ADC filter capacitor on the divided sense node.
- Pull `CHG_STAT_N` and `PGOOD_N` up to local +3V3.
- Verify whether the selected charger outputs are open-drain and active-low.
- Add test points for all telemetry nets.

USB D+/D− and CC1/CC2 do not pass through this telemetry connector.

---

## 14. Zone J — Mandatory LED Battery Monitor

The five-segment front-panel battery display is a required Rev A feature.

Required STM32 signals:

| Net | MCU pin | Function |
|---|---|---|
| `BATT_LED1` | PB2 | Segment 1 |
| `BATT_LED2` | PA15 | Segment 2 |
| `BATT_LED3` | PB3 | Segment 3 |
| `BATT_LED4` | PB4 | Segment 4 |
| `BATT_LED5` | PB5 | Segment 5 |
| `S801_BATT` | PC6 | Battery-display mode detection |

The LED interface must also use:

- `VBAT_SENSE`
- `CHG_STAT_N`
- `PGOOD_N`

### Required behavior

- In BATT mode, display pack state of charge.
- While external USB power is valid and charging is active, provide the defined
  charging animation.
- When charging is complete, indicate full state according to firmware design.
- Outside BATT mode, release all five LED-drive pins to high impedance.
- Never contend with the original CX10043/VU circuitry.

### Required bench confirmation

Before final wiring:

1. Determine LED common polarity.
2. Confirm current direction through the existing 180 ohm resistors.
3. Confirm what the CX10043 outputs do in BATT mode.
4. Confirm whether direct STM32 drive is safe.
5. Add transistor or open-drain buffers if direct drive would exceed STM32 limits or
   contend with the original circuitry.
6. Confirm the electrical state of `S801_BATT`.

The LED monitor is not DNP and is not a future option.

---

## 15. Sony Servo Interface Connector

Use a dedicated harness for the signals that replace CX20084 functions.

Minimum signal set:

| Net | Direction |
|---|---|
| `FG_RAW` | Sony to Servo Board |
| `Q601_BASE` | Servo Board to Sony |
| `MOTOR_EN_RAW` | Sony to Servo Board |
| `RV601_RAW` | Sony to Servo Board |
| `RV602_RAW` | Sony to Servo Board |
| `RV603_RAW` | Sony to Servo Board |
| GND | Shared |

S601 and the LED-board interface may use separate connectors if that better matches
the physical installation.

Do not claim a connector family or pitch until the actual harness, available space,
and installation method are fixed.

---

## 16. SWD and Recovery Header

SWD is mandatory even though USB firmware update is also mandatory.

Minimum connections:

| Pin | Signal |
|---|---|
| 1 | GND |
| 2 | SWDCLK |
| 3 | SWDIO |
| 4 | NRST |
| 5 | +3V3 reference |

A compact Tag-Connect or equivalent footprint is acceptable.

The +3V3 pin is a reference unless the programming procedure explicitly allows
external target power.

Keep the recovery connector accessible during Rev A development.

---

## 17. Required Test Points

| Test point | Net |
|---|---|
| TP_B1 | `B+1` |
| TP_B3 | `B+3` |
| TP_3V3 | `+3V3` |
| TP_GND | GND |
| TP_FG_RAW | `FG_RAW` |
| TP_FG_IN | `FG_IN` |
| TP_MOTOR_PWM | `MOTOR_PWM` |
| TP_Q601_BASE | `Q601_BASE` |
| TP_MOTOR_EN_RAW | `MOTOR_EN_RAW` |
| TP_MOTOR_EN_MON | `MOTOR_EN_MON` |
| TP_RV601 | conditioned RV601 |
| TP_RV602 | conditioned RV602 |
| TP_RV603 | conditioned RV603 |
| TP_USB_DP | `USB_DP` |
| TP_USB_DM | `USB_DM` |
| TP_CC1 | `CC1` |
| TP_CC2 | `CC2` |
| TP_VBAT_SENSE | `VBAT_SENSE` |
| TP_CHG | `CHG_STAT_N` |
| TP_PGOOD | `PGOOD_N` |
| TP_NRST | NRST |
| TP_SWDIO | SWDIO |
| TP_SWDCLK | SWDCLK |

---

## 18. ERC and Review Targets

Before layout:

- The root schematic is one flat D-size sheet.
- No charger, cells, pack protection, TPS63070, B+1 generator, barrel jack, IP2721,
  or 9 V PD path remains.
- B+1 enters through the CP304 interface.
- B+3 and +3V3 are generated locally.
- USB D+/D− and CC1/CC2 are present and owned by the Servo Board.
- No USB VBUS power rail powers the Servo Board.
- Both CC pins have a valid 5 V sink strategy.
- USB ESD and physical routing are defined.
- NRST, SWDIO, and SWDCLK are accessible.
- BOOT0 is not incorrectly tied to both rails.
- LED battery monitor circuitry is present and mandatory.
- All unmeasured Sony-facing values are clearly marked provisional.
- Externally driven rails have appropriate PWR_FLAGs or justified ERC treatment.
- ERC has no unexplained errors.

---

## 19. Standalone Bring-Up Order

1. Continuity checks with no power.
2. Verify no B+1-to-GND, B+3-to-GND, or +3V3-to-GND short.
3. Apply current-limited 6 V B+1 with no Sony signal harness connected.
4. Verify +3V3.
5. Verify B+3 into a dummy load.
6. Program the STM32 over SWD.
7. Verify USB enumeration and firmware update without motor connection.
8. Verify CC orientation handling with both USB-C plug orientations.
9. Inject known FG test signals and verify timer capture.
10. Inject known ADC voltages into each conditioned speed input.
11. Verify motor-enable monitor thresholds.
12. Verify motor-output safe state during reset, bootloader, USB attach, and firmware
    update.
13. Exercise Q601 output into a dummy load.
14. Verify Power Board telemetry inputs.
15. Verify LED monitor behavior with a bench LED/test load.
16. Bench-characterize the actual Sony Q601 and control nodes.
17. Connect to the WM-D6C only after all standalone tests pass.

---

## Commit Template

```text
git add hardware/kicad/DSR-1 docs/hardware/kicad-schematic-guide.md
git commit -m "Revise Servo Board guide for locked Rev A architecture"
```

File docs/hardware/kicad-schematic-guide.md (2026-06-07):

# DSR-1 Servo Control Board — KiCad 10 Schematic Guide

**Project:** `hardware/kicad/DSR-1/` — WM-D6C Capstan Servo Control Board (DSR-1)
**Tool:** KiCad 10.x
**Scope:** Servo Control Board schematic only. The Power Board has its own KiCad project.

> This document is the working guide for translating the DSR-1 **Servo Control Board**
> design into a KiCad 10 schematic. Read each zone before drawing it. The signal
> chain analysis, interface contract, and power architecture documents are the
> authoritative sources for all component values — this document tells you *how*
> to enter them in KiCad, not *why* they are what they are.
>
> **Schematic status:** the repository now carries two KiCad projects:
> `hardware/kicad/DSR-1` for the Servo Control Board and
> `hardware/kicad/Power-Board/wm-d6c-power-board` for the Power Board. Use this
> guide as the Servo Control Board entry guide and the cross-board net contract.
>
> **Two KiCad projects.** The final manufacturing direction is a separate **Power
> Board** and **Servo Control Board**. The Power Board schematic lives in
> `hardware/kicad/Power-Board/wm-d6c-power-board/`. This guide covers the Servo
> Control Board only — the board that fits in the CP304 cavity in all three builds.
> Use `docs/hardware/kicad-power-board-guide.md` for the Power Board schematic.

---

## Compatibility Scope

DSR-1 targets the full WM-D6C / TC-D6C production run (1984–2002). Two distinct
servo circuit families exist across that run:

| Family | Servo IC | Motor drive | Years (approx.) | Governing manual |
|---|---|---|---|---|
| **Ver. 1.0** (primary) | CX20084 | Single Q601 path; exact device/package pending on the SMD target unit | 1984–mid 2001 | `fb4872.pdf` |
| **Ver. 1.1** (planned variant) | CX-069A | Q601–Q605 (five transistors) | mid 2001–2002 | `sony_wm-d6c_tc-d6c_ver-1.1.pdf` |

**Rev A targets Ver. 1.0 boards.** This covers the majority of surviving units.
CX-069A board support is planned as a separate variant and is out of scope for
Rev A schematic capture.

Within Ver. 1.0, there are two PCB construction generations:

| Sub-generation | Approx. years | Construction |
|---|---|---|
| Early through-hole | 1984–~1994 | Through-hole PCB |
| Later SMD | ~1994–2001 | SMD main board |

Both sub-generations have the same CX20084-based servo function, but the actual target
unit is the later surface-mount construction with PCB marking `C11-494-12`. Treat
harness routing, pad geometry, and Q601 package/marking as pending physical mapping
until installation documentation is written from photos and bench measurements.

**To identify board family before installation:** open the machine and read the
IC at position IC601. CX20084 = Ver. 1.0 (proceed with this guide). CX-069A =
Ver. 1.1 (do not install Rev A; wait for Ver. 1.1 variant documentation).

---

## Prerequisites

Before opening KiCad:

1. `.gitignore` is committed (excludes `*-backups/`, `fp-info-cache`, `*.lock`,
   `*_autosave.*`)
2. `hardware/datasheets/` contains `stm32g0c1cc.pdf` (DS13560 Rev 6), `mt3608.pdf`,
   `fb4872.pdf`, and `sony_wm-d6c_tc-d6c_ver-1.1.pdf`
3. The `DSR-1.kicad_sym` project symbol library has been created and registered
   under Project scope in Preferences → Manage Symbol Libraries
4. Custom power symbols `B+1` and `B+3` have been created in `DSR-1.kicad_sym`
   with pin type **Power input**, pin number and name hidden, flagpole graphic body
5. Page size set to **D** (File → Page Settings → Page size **D**) — the whole design is one flat sheet

---

## KiCad Shortcut Reference

| Action | Shortcut |
|---|---|
| Add symbol | `A` |
| Add wire | `W` |
| Add net label | `L` |
| Add power port | `P` |
| Mirror horizontal | `X` |
| Mirror vertical | `Y` |
| Edit properties | `E` |
| Run ERC | Inspect → Electrical Rules Checker |
| Add no-connect flag | `Q` |

---

## Single-Sheet Layout (D-size)

Each KiCad project has exactly **one flat schematic sheet**. The Servo Control Board
is one D-size sheet in `hardware/kicad/DSR-1/`; the Power Board is one sheet in
`hardware/kicad/Power-Board/wm-d6c-power-board/`. Do not confuse that with the older
all-in-one project: power management and battery charging belong in the separate
Power Board project.

Organize the Servo Control Board canvas into three visual **zones**, left-to-right by signal flow. Zones are
just same-sheet regions (optionally boxed with a graphic rectangle + text label);
they are not KiCad sheets and carry no electrical meaning:

```
┌─ Microcontroller ─┐ ┌─ Signal Conditioning ─┐ ┌─ Connectors ─────────────┐
│ STM32G0C1KCU6     │ │ FG divider + clamp    │ │ J1 harness              │
│ decoupling, boot, │ │ NPN motor drive       │ │ J_BBL Power Board link  │
│ pin assignments   │ │ ADC clamps            │ │ J2 SWD / J3 LED board   │
│ USB / ADC / PWM   │ │ VBAT sense input      │ │ test pads               │
└───────────────────┘ └───────────────────────┘ └──────────────────────────┘
```

The sections below are written per zone. Component values come from the design docs
(signal-chain analysis, interface contract, power-supply design); this guide tells you
how to enter them.

---

## Net Labeling

On a single sheet, connectivity is trivial — **a net label connects to every identical
label anywhere on the sheet.** There are no hierarchical labels, sheet pins, or global
labels to manage; do not use multi-sheet hierarchy for either project.

- **Net labels (`L`)** — name any net you want to join by name instead of a drawn wire
  (`FG_IN`, `MOTOR_PWM`, `VBAT_SENSE`, `BATT_LED1`, …). Same name = same net. Use them
  to avoid long cross-zone wires.
- **Power symbols (`P`)** — `B+1`, `B+3`, `+3V3`, `GND` connect globally by symbol.
  Place a PWR_FLAG at each rail's source so ERC sees it driven.
- **Local wiring** — short within-zone nets can just be wires; reserve labels for
  signals that cross zones.

Every net is traceable end-to-end with no import/export step — which removes the most
common ERC pitfall of the old hierarchical layout ("net has no driver / not imported").

---

## Power Board Interface

**Purpose:** document only the nets that cross from the separate Power Board project
into this Servo Control Board project. Do not draw USB-C input, PD trigger, charger,
cell protection, B+1 regulation, B+3 generation, or 3.3V regulation in the DSR-1
schematic.

The Power Board schematic is the single sheet in
`hardware/kicad/Power-Board/wm-d6c-power-board/`. Its local power nets, including
`VBUS`, `9V_PD`, `B+1_RAW`, `V_SYS`, and `VBAT`, stay in that project unless they are
explicitly exported through a connector.

See `docs/hardware/kicad-power-board-guide.md` for the Power Board entry guide.

Servo Control Board interface nets:

| Net | Direction | DSR-1 entry point | Notes |
|---|---|---|---|
| `VBAT_SENSE` | Power Board → Servo Control Board | J_BBL → PB0/ADC_IN8 | Scaled pack-voltage sense |
| `VBAT_SENSE_EN` | Servo Control Board → Power Board | PB1 → J_BBL | Gates the Power Board sense divider |
| `CHG_STAT` | Power Board → Servo Control Board | J_BBL → PB7 | BQ24074 charge status, low while charging |
| `PGOOD` | Power Board → Servo Control Board | J_BBL → PB8 | BQ24074 power-good status |
| `USB_DM` / `USB_DP` | Bidirectional | J_BBL → PA11/PA12 | Optional if the Power Board USB-C connector carries CDC/service data |
| `CC1` / `CC2` | Bidirectional/monitor | J_BBL → PA8/PA9 | Optional only if the Servo MCU monitors or participates in Type-C/UCPD |

Power rails that feed the Servo Control Board arrive through the WM-D6C battery-terminal
and CP304 harness path, not through a local power-entry zone in this schematic.

---

## Microcontroller Zone (STM32G0C1)

**Purpose:** STM32G0C1KCU6 and all support components. Place the STM32 in the
centre and work outward.

### U1 — STM32G0C1KCU6 (UFQFPN32)

Use the KiCad `MCU_ST_STM32G0` library symbol `STM32G0C1KCUx`, copied to
`DSR-1.kicad_sym` and renamed `STM32G0C1KCU6`. The UFQFPN-32 package has
**1 VDD and 1 VSS** in the 32-pin K package. VDD and VDDA share one pin;
VSS and VSSA share one pin. Expose the thermal pad (EP) as described below.

> **VDDIO2 confirmed absent in the GP variant.** STM32G0C1KCU6 (_KxU) has VDDIO2
> tied to VDD internally — no separate VDDIO2 pin, no additional decoupling needed.
> (stm32g0c1cc.pdf Figure 4, GP version confirmed.)

**UFQFPN-32 GP (_KxU) confirmed pin map — DS13560 (stm32g0c1cc.pdf):**

| Pin | Name | DSR-1 assignment |
|-----|---|---|
| 1 | PB9 | No-connect |
| 2 | PC14-OSC32_IN | No-connect |
| 3 | PC15-OSC32_OUT | No-connect |
| 4 | VDD/VDDA | `+3V3` (combined) |
| 5 | VSS/VSSA | GND (combined) |
| 6 | PF2-NRST | Reset — 100nF to GND |
| 7 | PA0 | `FG_IN` / TIM2_CH1 |
| 8 | PA1 | `RV601_WIPER` / ADC_IN1 |
| 9 | PA2 | `RV602_WIPER` / ADC_IN2 |
| 10 | PA3 | `RV603_WIPER` / ADC_IN3 |
| 11 | PA4 | No-connect (DAC1_OUT1 — not used, see note) |
| 12 | PA5 | `MOTOR_EN_MON` / GPIO |
| 13 | PA6 | `MOTOR_PWM` / TIM3_CH1 |
| 14 | PA7 | `SPEED_TUNE_SW` / GPIO |
| 15 | PB0 | `VBAT_SENSE` / ADC_IN8 (battery) |
| 16 | PB1 | `VBAT_SENSE_EN` / GPIO sense-gate (battery) |
| 17 | PB2 | `BATT_LED1` / GPIO·TIM (battery) |
| 18 | PA8 | `CC1` / UCPD1_CC1, UCPD1_DBCC1 |
| 19 | PA9 | `CC2` / UCPD1_CC2 |
| 20 | PC6 | `S801_BATT` / GPIO in (battery) |
| 21 | PA10 | No-connect / spare |
| 22 | PA11 [PA9] | `USB_DM` |
| 23 | PA12 [PA10] | `USB_DP` |
| 24 | PA13 | `SWDIO` |
| 25 | PA14-BOOT0 | `SWDCLK` |
| 26 | PA15 | `BATT_LED2` / GPIO·TIM (battery) |
| 27 | PB3 | `BATT_LED3` / GPIO·TIM (battery) |
| 28 | PB4 | `BATT_LED4` / GPIO·TIM (battery) |
| 29 | PB5 | `BATT_LED5` / GPIO·TIM (battery) |
| 30 | PB6 | `DEBUG_TX` / USART1_TX |
| 31 | PB7 | `CHG_STAT` / GPIO in — BQ24074 CHG status (low while charging; battery build) |
| 32 | PB8 | `PGOOD` / GPIO in — BQ24074 power-good status (battery build) |
| EP | VSS | GND — expose this pin in Symbol Editor; via array in layout |

> **PB15 does not exist in the GP variant** (_KxU). PB15 is only present in
> the N variant (_KxUxN). The previous guide entry "PB15 / UCPD1_CC2" was
> wrong. CC2 → PA9 (pin 19) for UCPD1_CC2.
>
> **DEBUG_TX moved from PA9 to PB6.** PA9 is required for UCPD1_CC2 and cannot
> simultaneously serve USART1_TX. PB6 (pin 30) carries USART1_TX and is
> available.
>
> **VDDIO2 confirmed absent** in GP variant. Pin 20 = PC6. No VDDIO2 decoupling
> needed. (stm32g0c1cc.pdf Figure 4, GP version _KxU confirmed.)

> **PA4 (DAC1_OUT1) is not used for motor drive.** Motor drive uses TIM3 PWM on PA6
> through the NPN level-shift stage on the Signal Conditioning zone. Q601 exact
> part/package and base-voltage range remain pending bench verification on the
> C11-494-12 SMD board. PA4 may be left unconnected with a no-connect flag or reserved
> as a spare ADC-capable pin.

**Unused pins:** Place a No-Connect flag (`Q`) on every unused GPIO pin.

---

> **Battery-build pins:** pins 15–17, 20, 26–29, and 31–32 carry the battery level
> indicator and charge-status signals (No-connect on wall-only builds). LED segment
> pins on timer channels can PWM-dim the bar (night dimming, charge animation); plain
> GPIO gives on/off segments. Reconcile with `stm32g0c1-pin-allocation.md`.

### Decoupling Network

**VDD/VDDA decoupling (pin 4 — combined supply in 32-pin package):**
- 100nF 10V X5R 0402 — power supply decoupling
- 100nF 10V C0G 0402 — analog noise filtering (C0G/NP0, lower noise than X5R)
- 1µF 10V X5R 0402 — bulk bypass

All three caps connect between pin 4 and GND. The C0G cap should be placed
closest to the pin on the PCB as it serves the ADC inputs.

> **VDDIO2:** Absent in the STM32G0C1KCU6 GP variant (_KxU). No additional
> decoupling needed — VDDIO2 is tied to VDD internally.

All capacitor GND terminals connect directly to the nearest GND power symbol.

---

### Boot and Reset

**BOOT0 (PA14-BOOT0 — shared with SWDCLK):**

```
+3V3 ──[10kΩ]────┬── BOOT0
                  │
                 GND (holds BOOT0 low = normal boot from flash)
```

**NRST:**
- 100nF to GND; no external reset button on Rev A unless space allows
- Add no-connect flag if not bringing out to a test point

---

### Net labels used in this zone

**Inputs:**
- `USB_DP`, `USB_DM`, optional `CC1`, `CC2` ← the Connectors zone via J_BBL Power Board link
- `FG_IN`, `RV601_WIPER`, `RV602_WIPER`, `RV603_WIPER`, `MOTOR_EN_MON` ← the Signal Conditioning zone
- `SPEED_TUNE_SW`, `SWDIO`, `SWDCLK` ← the Connectors zone

**Outputs:**
- `MOTOR_PWM` → the Signal Conditioning zone

**Battery build:**
- Inputs: `VBAT_SENSE`, `S801_BATT`, `CHG_STAT`, `PGOOD`
- Outputs: `VBAT_SENSE_EN`, `BATT_LED1`…`BATT_LED5`

---

## Signal Conditioning Zone

**Purpose:** Every analog interface between the STM32 and the machine. Conditions
incoming machine-voltage signals down to 3.3V; level-shifts STM32 PWM output up
to drive the machine's motor transistor.

### FG Signal Path (J1 Pin 1 → PA0)

FG901 GP2S22AB is an open-collector optical interrupter. Its output is pulled to
B+1 (~6V) through a resistor on the WM-D6C main board. The swing is approximately
0 to 5.9V — exceeding the STM32's 3.6V absolute maximum input.

```
FG_RAW (from the Connectors zone, J1 pin 1)
    │
   [R3: 10kΩ 1% 0402]
    │
   [R4: 22kΩ 1% 0402] ──── GND        ← voltage divider lower leg
    │
   ├──[D_FG1: BAT54S, anode→node, cathode→+3V3]   ← high-side clamp (BAT54S = dual SOT-23; one package serves both clamps)
   ├──[D_FG2: BAT54S, anode→GND, cathode→node]    ← low-side clamp
   │
   [C7: 10pF C0G 0402] ──── GND        ← motor-brush noise filter
    │
   FG_IN (net label → the Microcontroller zone, PA0)
```

Divider math: V_node = V_FG × 22/(10+22) = V_FG × 0.6875
At 5.9V swing: 5.9 × 0.6875 = 4.06V → BAT54S clamps to ≤3.6V ✓

Schematic note: `⚠ VERIFY ACTUAL FG SWING ON BENCH BEFORE POWER-ON.
R4 value may need adjustment based on measured B+1 and pull-up resistor.
See signal-chain-analysis.md §1 for formula. Do not connect FG directly
to PA0 without confirming the conditioned voltage is below 3.3V.`

---

### Motor Drive Output (PA6 → J1 Pin 2 → Q601 base)

Q601 is the off-board WM-D6C motor-control device driven from the former CX20084
output node. On the actual C11-494-12 SMD board its exact package/marking and
base-voltage range must be physically confirmed. The STM32 3.3V PWM output does not
drive this node directly — a level-shift stage using a small-signal NPN (Q_LS) is
the committed topology.

**Boot-safe behavior:** At reset, TIM3 PWM defaults to 0% duty cycle. Q_LS is
off. R9 pulls Q601's base toward B+1 (6V). Vbe = 6V − 10.8V = −4.8V — Q601
is firmly off. Motor cannot run uncontrolled during boot or firmware update.

```
MOTOR_PWM (from the Microcontroller zone, PA6 TIM3_CH1, 15.6 kHz)
    │
   [R7: 1kΩ 5% 0402]
    │
    ├──[C8: 100nF 10V X5R 0402] ──── GND    ← PWM-to-analog RC filter
    │                                          fc = 1/(2π×1kΩ×100nF) = 1.59 kHz
    │
   Q_LS base (MMBT3904 NPN, SOT-23)
   Q_LS emitter → GND
   Q_LS collector
    │
   [R8: 10kΩ 5% 0402] ──── [Q601_BASE net / J1 pin 2]
    │
   [R9: 100kΩ 5% 0402] ──── B+1 power symbol
    │
   Q601_BASE (net label → the Connectors zone, J1 pin 2)
```

Q_LS is the MMBT3904 NPN on the DSR-1 board. Q601 is on the WM-D6C main board — use
a generic off-board motor-control symbol and note `Q601 exact package/marking pending
bench confirmation`.

Schematic note: `Q601 is on WM-D6C main board — NOT on DSR-1 PCB.
Q601 emitter → B+3 via Q703/Q704 mode-switch chain. Q601 base operating range
must be measured on bench to confirm R9 sizing. See signal-chain-analysis.md §2.`

---

### Motor Enable Monitor (J1 Pin 3 → PA5)

The MOTOR_EN signal at the IC601 footprint pin 7 pad is held HIGH (~4.4V) during
playback via R605 (pullup to B+1). Q702 on the auto-off board pulls it LOW at
end-of-tape or auto-off. After IC601 is removed, this signal is accessible at
the IC601 footprint pin 7 pad or the R605 junction.

```
MOTOR_EN (from the Connectors zone, J1 pin 3)
    │
   [R_EN1: 10kΩ 1% 0402]
    │
   [R_EN2: 22kΩ 1% 0402] ──── GND
    │
   MOTOR_EN_MON (net label → the Microcontroller zone, PA5)
```

Divider: 22/(10+22) = 0.6875. At 4.4V playback: 3.025V ≤ 3.3V ✓
At auto-off (low): ≈0.2V, below VIL ✓

Schematic note: `MOTOR_EN tap point: IC601 footprint pin 7 pad on WM-D6C main
board. Verify voltage on bench before connecting. See signal-chain-analysis.md §3.`

---

### ADC Inputs — RV601, RV602, RV603 (J1 Pins 4, 5, 6 → PA1, PA2, PA3)

Each potentiometer wiper may be referenced to B+1 and could exceed 3.3V.
The 100Ω series resistor plus BAT54S clamp is the minimum safe configuration.

**⚠ Measure wiper voltage on bench before first power-on.** If any wiper exceeds
3.3V at B+1 = 6V, add a resistor divider before the clamp.

```
RV601 (from the Connectors zone, J1 pin 4)
    │
   [R_ADC1: 100Ω 5% 0402]              ← source impedance limit + protection
    │
   ├──[BAT54S, anode→node, cathode→+3V3]  ← overvoltage clamp
   ├──[BAT54S, anode→GND, cathode→node]   ← undervoltage clamp
    │
   RV601_WIPER (net label → the Microcontroller zone, PA1/ADC_IN1)
```

Repeat identically for RV602 → PA2 and RV603 → PA3.

Schematic note: `⚠ VERIFY WIPER VOLTAGE BEFORE POWER-ON. See signal-chain-
analysis.md §4 for divider formula. If wiper exceeds 3.3V, add R/2R divider
before the 100Ω series resistor. Adjust ADC scaling in firmware to match.`

---

### Battery Sense (VBAT → ADC) — battery build

> **VBAT is on the Power Board.** In the battery-integrated build, the raw pack
> voltage (VBAT) lives on the Power Board's VBAT node. It arrives at the Servo Control
> Board as `VBAT_SENSE` via the board-to-board link — a wire from the Power Board
> board's sense tap to PB0 on the Servo Control Board. The divider and sense-gate below
> sit on the **Servo Control Board** (receiving end).

```
VBAT_SENSE (from Power Board board-to-board link)
    │
   [C_VS: 10nF C0G 0402] ──── GND     (at the VBAT_SENSE node)
    │
   ┌─ ADC_IN8 / PB0 (Microcontroller zone)
   │
[R_VS1: 33kΩ 1% 0402] ──┬── above node
                         │
                     [R_VS2: 100kΩ 1% 0402]
                         │
                     Q_VS drain  (2N7002 N-FET; gate ← VBAT_SENSE_EN / PB1; source → GND)
```

- **33kΩ / 100kΩ divider** (updated from 22k for the LiPo 4.2V peak): ratio
  100/133 = 0.75 → 4.2V float presents ~3.16V to ADC (under 3.3V VDDA with margin);
  3.0V floor → ~2.26V. LiPo discharge curve (4.2V → 3.0V) is usefully sloped, so
  voltage-based SoC is more reliable here than on the flat LFP curve.
- Q_VS gates the divider's ground leg so it draws ~0 except during a measurement
  (firmware raises `VBAT_SENSE_EN`, settles, samples, lowers) — no standby drain on
  the pack. Q_VS source sits on the servant board module schematic; it drains down
  through R_VS2.
- Schematic note: `Source impedance ~25kΩ — allow adequate ADC sample time (≥10µs
  sample time at 64MHz). LiPo OCV table in firmware; sloped 4.2V→3.0V curve gives
  reliable SoC. VBAT arrives via board-to-board link from the Power Board. See §7.8.`

**Battery level indicator drive:** the five `BATT_LED1…5` lines route from the
Microcontroller zone to J3 (Connectors zone) and on to the WM-D6C LED board. Optional
small series resistors per line may go here; the existing 180Ω limiters (R814–818) live
on the LED board. `S801_BATT` is the MCU enable flag: drive these lines only while
S801 is in BATT, and release/high-Z them in VU/non-BATT modes so the MCU does not
contend with the CX10043 circuitry. CHG_STAT and PGOOD (PB7/PB8) drive the charge
animation — segments march upward while PGOOD is high and CHG_STAT is low (charging);
hold full when CHG_STAT goes high (done).

### Net labels used in this zone

**Inputs (from other same-sheet zones):**
- `MOTOR_PWM` ← the Microcontroller zone (PA6)
- `FG_RAW`, `MOTOR_EN`, `RV601`, `RV602`, `RV603` ← the Connectors zone

**Outputs (to other same-sheet zones):**
- `FG_IN` → the Microcontroller zone (PA0)
- `RV601_WIPER`, `RV602_WIPER`, `RV603_WIPER` → the Microcontroller zone
- `MOTOR_EN_MON` → the Microcontroller zone
- `Q601_BASE` → the Connectors zone (J1 pin 2)

**Battery build:**
- `VBAT_SENSE_EN` ← the Microcontroller zone; `VBAT_SENSE` → the Microcontroller zone

---

## Connectors Zone

**Purpose:** Physical boundaries of the board. All connectors and headers.
No signal conditioning — just mechanical connections and net labels.

### J1 — 8-pin JST SH 1.25mm (WM-D6C Interface Harness)

Symbol: `Connector_JST:JST_SH_SM08B-SRSS-TB_1x08-1MP_P1.00mm_Horizontal`
or equivalent 8-pin 1.25mm JST SH footprint.

| J1 Pin | Net Label | Signal | Direction |
|---|---|---|---|
| 1 | `FG_RAW` | FG901 optical sensor output | machine → Servo Control Board |
| 2 | `Q601_BASE` | Motor drive to Q601 base | Servo Control Board → machine |
| 3 | `MOTOR_EN` | MOTOR_EN net (IC601 pin 7 pad) | machine → Servo Control Board |
| 4 | `RV601` | RV601 wiper (base speed trim) | machine → Servo Control Board |
| 5 | `RV602` | RV602 wiper (Speed Tune slider) | machine → Servo Control Board |
| 6 | `RV603` | RV603 wiper (Speed Tune range) | machine → Servo Control Board |
| 7 | `B+1` power symbol | 6V supply rail | Shared |
| 8 | GND power symbol | Chassis ground | Shared |

Pin 7 and Pin 8 use power symbols, not net labels.

**Series diode on J1 pin 7 (B+1 supply line):**

```
B+1 power symbol ──[D_B1: 1N5819, anode]──[cathode]── J1 pin 7
```

Schematic note: `D_B1 prevents reverse current from Sony B+1 rail into DSR-1
converter when Sony is powered and DSR-1 is not. Forward drop ~0.3V at load
current. Machine sees ~5.7V on B+1 — within specification.`

**S601 Speed Tune switch — direct connection, no level shift:**

S601 is rewired to operate at 3.3V logic level. Connect one terminal to `+3V3`
and the other to `SPEED_TUNE_SW`. STM32 PA7 is configured with internal pull-down.
No external components needed.

```
+3V3 ──[S601 switch]── SPEED_TUNE_SW (→ the Microcontroller zone, PA7)
                        │
                       [PA7 internal pull-down ~40kΩ to GND]
```

This pin does not route through J1 — S601 is rewired during installation to
connect directly to the DSR-1 board.

---

### J2 — SWD Debug Header (4-pin 2.54mm, 1×4)

Symbol: `Connector:Conn_01x04_Pin`

| J2 Pin | Net Label | Signal |
|---|---|---|
| 1 | GND | Ground |
| 2 | `SWDCLK` | SWD clock |
| 3 | `SWDIO` | SWD data |
| 4 | `+3V3` | 3.3V reference only |

Schematic note: `J2: SWD programming header. Use STM32CubeProgrammer or OpenOCD.
3.3V pin is reference only — do not use to power the board. Do not bury this
header under the installed board; keep accessible during Rev A development.`

---

### J3 — LED-Board Harness (battery indicator), 7-pin

| J3 Pin | Net | Signal | Direction |
|---|---|---|---|
| 1 | `BATT_LED1` | LED D801 drive | Servo Control Board → machine |
| 2 | `BATT_LED2` | LED D802 drive | Servo Control Board → machine |
| 3 | `BATT_LED3` | LED D803 drive | Servo Control Board → machine |
| 4 | `BATT_LED4` | LED D804 drive | Servo Control Board → machine |
| 5 | `BATT_LED5` | LED D805 drive | Servo Control Board → machine |
| 6 | `S801_BATT` | S801 BATT-position sense | machine → Servo Control Board |
| 7 | GND | Common / return | Shared |

> Schematic note: `⚠ Bench-confirm before wiring J3 (power-supply-design.md §7.8):
> (1) how S801's BATT position reroutes D801–D805 and whether the CX10043 outputs go
> high-impedance there (so the STM32 drives them without contention); (2) LED common
> polarity through the on-board 180Ω limiters, to set drive direction. `S801_BATT`
> gates ownership: MCU outputs are released/high-Z in VU/non-BATT modes.`

### J_BBL — Board-to-Board Link (battery build only)

A small polarised connector carrying status, sense, and optional USB/service signals
between the Power Board and this Servo Control Board. **DNP on wall-only builds.**
Use a latching, foolproof connector. It does not carry the B+1 power rail.

| J_BBL Pin | Net | Dir | Description |
|---|---|---|---|
| 1 | GND | Shared | Common ground return |
| 2 | `VBAT_SENSE` | Power Board → Servo Control Board | LiPo pack voltage sense (33kΩ/100kΩ divider; see Signal zone) |
| 3 | `VBAT_SENSE_EN` | Servo Control Board → Power Board | Gate control for Power Board sense divider (PB1 GPIO) |
| 4 | `CHG_STAT` | Power Board → Servo Control Board | BQ24074 CHG status — low while charging (PB7 GPIO) |
| 5 | `PGOOD` | Power Board → Servo Control Board | BQ24074 power-good status (PB8 GPIO) |
| 6 | `USB_DM` *(optional)* | Bidirectional | CDC tuning, if USB-C is on Power Board |
| 7 | `USB_DP` *(optional)* | Bidirectional | CDC tuning, if USB-C is on Power Board |
| 8 | `CC1` *(optional)* | Bidirectional/monitor | UCPD/Type-C monitoring if the Servo MCU participates |
| 9 | `CC2` *(optional)* | Bidirectional/monitor | UCPD/Type-C monitoring if the Servo MCU participates |

Schematic note: `J_BBL: board-to-board link to Power Board (battery build).
DNP for Variant A and Variant B wall builds. B+1 and GND are NOT on this connector —
they travel via the battery-terminal injection point on the WM-D6C main board and the
CP304 harness. USB and CC pins populate only if service data or UCPD monitoring routes
through the Power Board USB-C connector rather than a bench header.`

---

### Test Pads

Add `Device:TestPoint` for each of:

| Reference | Net | Purpose |
|---|---|---|
| TP1 | `+3V3` | MCU supply check |
| TP2 | `B+3` | Motor supply check |
| TP3 | `FG_RAW` | FG oscilloscope probe point |
| TP4 | `Q601_BASE` | Motor drive output check |
| TP5 | `DEBUG_TX` | UART debug / PB6 |
| TP6 | GND | Scope ground reference |

---

## Annotation Scheme

The design is one flat sheet, so annotate in a single pass: Tools → Annotate Schematic
→ Annotate. A single sequential pass is fine; for readability you can group designators
by zone by assigning ranges as you place parts. If parts are moved between zones,
re-run Annotate to resolve duplicate designators; gaps are harmless.

## Symbol Properties Checklist

Before running ERC, verify every symbol has:

| Field | Example |
|---|---|
| **Value** | `169kΩ`, `STM32G0C1KCU6`, `MMBT3904` |
| **Footprint** | `DSR-1:STM32G0C1KCU6_UFQFPN32` |
| **Datasheet** | relative path in `hardware/datasheets/` or URL |
| **LCSC** | JLCPCB part number (custom field) |
| **DNP** | `Variant A only`, `Variant B only`, or blank for shared |

---

## ERC — Expected Errors and Resolutions

Run Inspect → Electrical Rules Checker after completing the single schematic sheet.

| Error | Cause | Resolution |
|---|---|---|
| Power pin not driven | Missing PWR_FLAG | Add PWR_FLAG on B+1, B+3, +3V3 at the rail source |
| Pin unconnected | Unused STM32 GPIO | Add No-Connect flag (`Q`) |
| Net has no driver | Net-label typo or missing PWR_FLAG | Check label spelling; add PWR_FLAG at the rail source |
| Conflicting net | Duplicate label names | Ensure all labels are unique or intentionally shared |

Target: **zero errors** before moving to PCB layout. Warnings on properly-flagged
DNP open pins are acceptable.

---

## First Commit After Schematic Completion

```
git add hardware/kicad/
git commit -m "DSR-1 Rev A schematic — single D-size sheet, ERC clean, pre-layout

- Single flat D-size sheet (no hierarchy)
- MCU zone: STM32G0C1KCU6 decoupling, pin assignments; motor PWM on PA6 (TIM3_CH1)
- Signal zone: FG divider/clamp, NPN motor drive, ADC clamps, VBAT sense
- Connectors zone: J1 harness, J_BBL Power Board link, J2 SWD, J3 LED board, S601 rewire, test pads
- Rev A targets Ver. 1.0 CX20084 boards (1984-2001)
- ERC: 0 errors"

git tag -a hw-v0.1-schematic-complete -m "Schematic complete, ERC clean, ready for layout review"
git push origin main --tags
```

---

## Distribution & Printing

A single D-size sheet does **not** require downstream users to own a large-format
plotter. For public release (CERN-OHL-P), ship readable artifacts alongside the KiCad
source:

- **Full-size schematic PDF** — `kicad-cli sch export pdf` renders the D-sheet to a PDF
  anyone can open and zoom/pan on screen, or tile-print across letter/A4 in their PDF
  reader's poster/tile mode. Screen review needs no paper at all.
- **(Optional) tiled letter/A4 PDF** — for bench/service use, provide a paginated PDF so
  a single page can sit next to the machine. Generate it in a release script rather than
  maintaining a second schematic by hand.
- **Release file set** — schematic PDF (readable by everyone) + `.kicad_sch`/project (for
  editors) + BOM + gerbers. The source's sheet size never reaches a plotter unless someone
  chooses to send it there.

Example export (from the project directory):

```
kicad-cli sch export pdf hardware/kicad/DSR-1/DSR-1.kicad_sch -o dist/DSR-1-schematic.pdf
```

---

## PCB Layout Priority Constraints

After ERC passes, update the PCB (Tools → Update PCB from Schematic) and begin
placement in this priority order:

1. STM32 decoupling caps within 0.5mm of the combined VDD/VDDA pin
2. J1 WM-D6C harness and J_BBL Power Board link placement with service clearance
3. USB differential pair, if populated: matched length, 90Ω differential impedance, short route to the MCU
4. B+3 motor drive traces: minimum 0.5mm width for 500mA
5. GND pour on both layers; via array under STM32 exposed VSS pad (2×2 or 3×3 grid, 0.3mm drill)
6. Analog signal region (FG, ADC, motor-drive monitor) kept away from PWM/base-drive and USB traces

See `signal-chain-analysis.md §10` for full layout rule derivations.

---

*Document version: 1.0 — Matches DSR-1 hardware Rev A*
*Replaces: initial draft (v0.1) — corrected motor drive topology, full production run scope added, schematic filenames aligned with actual KiCad project*
*v0.3: legacy all-in-one draft added battery-integrated charge-in-place notes and STM32-driven battery level indicator references. Superseded by the two-project split.*
*v0.4: legacy all-in-one draft consolidated power content before the two-project split; legacy multi-sheet numbering removed in later flat-sheet revisions.*
*v0.6: legacy battery appendix merged before power moved to its own KiCad project; single cohesive guide, no addendum.*
*v0.5: flattened to a single D-size sheet — hierarchy, root sheet, and sheet pins removed; zones replace sheets; added Distribution & Printing.*
*v0.7: chemistry swap LFP → LiPo; charger CN3058E → BQ24074 (DPPM power-path, R_ISET=1.1kΩ/0.8A, R_ILIM=800Ω/2A); protection HY2112-CB → DW01+FS8205; two-board architecture noted; **NOTE: v0.7 incorrectly renamed G0C1 → G0B1 throughout — reverted in v0.8.** CHG_STAT/PGOOD nets; VBAT_SENSE divider 22k→33k; LiPo OCV note; §7.8 cross-reference.*
*v0.8: two-project split — Servo Control Board guide only; Power Board content replaced with project/interface pointer; J_BBL board-to-board connector added to Connectors zone; **MCU corrected back to STM32G0C1KCU6** (verified against repo schematic STM32G0C1 and decoupling.kicad_sch, symbol MCU_ST_STM32G0:STM32G0C1KCUx, U5); DS reference updated; BAT54 → BAT54S (dual SOT-23, as placed in Signal conditioning.kicad_sch); intro updated for two-project structure.*
*v0.9: updated Servo/Power Board KiCad project paths; clarified that each project has one flat schematic sheet; clarified that `VBUS`/USB +5V is the default Type-C sink rail, not USB-C PD, and that `9V_PD` is Variant A only after IP2721 negotiation.*
*v1.0: removed the obsolete DSR-1 power region from this Servo Control Board guide; the DSR-1 sheet now has only Microcontroller, Signal Conditioning, and Connectors zones, with power content represented only by the J_BBL interface contract.*

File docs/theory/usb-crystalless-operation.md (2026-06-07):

# USB Crystal-Less Operation

## Purpose of This Document

Every USB device requires a precise 48 MHz clock to generate and decode USB Full
Speed signals. The conventional approach is an external quartz crystal — a small,
highly accurate resonator that vibrates at a known frequency. The DSR-1 Servo Control Board uses
no external crystal anywhere on the board. This document explains how USB 2.0 Full
Speed operation is achieved without one, why this matters specifically for the
WM-D6C project, and what the tradeoffs are.

---

## 1. Why USB Needs a Precise 48 MHz Clock

### 1.1 USB Full Speed Timing Requirements

USB Full Speed operates at 12 Mbit/s — each bit occupies 83.3 nanoseconds. The USB
2.0 specification requires that the transmitter's bit rate be accurate to ±2500 ppm
(parts per million) relative to the nominal 12 MHz bit clock, which is derived from
the 48 MHz USB clock by dividing by four. 2500 ppm represents 0.25% frequency
accuracy.

This sounds lenient, but consider the context. A quartz crystal oscillator typically
achieves ±20-100 ppm accuracy over temperature — ten to a hundred times better than
USB requires. RC oscillators in silicon, by contrast, are typically accurate to only
±1-5% without calibration — ten to fifty times worse than USB requires. The gap
between what an untrimmed RC oscillator delivers and what USB requires is the
problem that crystal-less operation must bridge.

The consequence of clock inaccuracy in USB is not graceful degradation — USB frames
will fail CRC checks, the host will retransmit, latency increases, and eventually
the device will enumerate unreliably or not at all. At 0.25% maximum error, there
is almost no margin: an RC oscillator at ±3% error is twelve times too inaccurate.

### 1.2 The Traditional Solution: External Crystal

In conventional USB device designs, a 12 MHz or 48 MHz quartz crystal is connected
to the microcontroller's oscillator input pins. The crystal's mechanical resonance
provides frequency accuracy of ±20-50 ppm, twenty to a hundred times better than
USB requires. This approach is reliable, well-understood, and cheap — a 12 MHz
crystal costs approximately $0.15 in quantity.

The WM-D6C presents a specific reason to avoid the crystal beyond general preference:
the machine has already suffered damage from improper handling and long-term storage.
Quartz crystals are mechanically fragile — a sharp mechanical shock can crack the
resonating element. A 35-year-old machine that has been dropped, stored poorly, or
subjected to the shock of incorrect adapter damage is exactly the scenario where a
crystal is at risk. Eliminating the crystal eliminates that failure mode from the
replacement board.

---

## 2. The STM32G0C1's Crystal-Less USB Architecture

### 2.1 The HSI48 Internal Oscillator

The selected STM32G0C1KCU6 contains an internal 48 MHz RC oscillator called HSI48 (High
Speed Internal 48 MHz). This is a dedicated oscillator for USB, separate from the
HSI16 that drives the system PLL. From DS13560 Rev 6, Table 45:

| Parameter | Value |
|---|---|
| Nominal frequency | 48 MHz |
| Factory calibration accuracy | ±3% at VDD = 3.0-3.6V, TA = -15 to 85°C |
| User trimming step | 0.11% to 0.18% per step |
| User trimming coverage | ±6% to ±7% total |
| Start-up time | 2.5µs typical, 6µs maximum |
| Power consumption | 340-380µA |

The ±3% factory calibration accuracy is far outside the USB requirement of ±0.25%.
Left untrimmed, the HSI48 cannot produce a clock accurate enough for USB. This is
where the Clock Recovery System (CRS) peripheral becomes essential.

### 2.2 The Clock Recovery System (CRS)

The CRS peripheral is a hardware frequency measurement and correction system built
into the STM32G0C1. It works by continuously comparing the HSI48 frequency against
a reference signal and automatically adjusting the HSI48 trim register to keep the
oscillator on target.

The reference signal can be sourced from several inputs. For USB crystal-less
operation, the reference is the USB Start-of-Frame (SOF) packet — a special USB
packet that the USB host (the computer or hub) sends exactly once per millisecond,
every 1.000ms ± 250ppm.

The CRS measures the number of HSI48 clock ticks between successive SOF packets.
If the USB clock were exactly 48 MHz and the SOF interval were exactly 1ms, there
would be exactly:

```
48,000,000 Hz × 0.001s = 48,000 ticks per SOF interval
```

If the HSI48 is running fast (say 48.5 MHz), the tick count between SOFs will be:

```
48,500,000 × 0.001 = 48,500 ticks  (500 more than expected)
```

The CRS detects this 500-tick excess (representing a +1.04% frequency error) and
decrements the HSI48 trim register to slow the oscillator down. On the next SOF
interval, the tick count is closer to 48,000. The CRS continues this correction
on every SOF packet — 1000 corrections per second.

### 2.3 The Math: CRS Accuracy

The USB host sends SOF packets at 1.000ms ± 250ppm intervals. The CRS uses this as
its frequency reference. The USB specification requires the device clock to be within
±2500 ppm of 48 MHz. The CRS achieves accuracy limited by the reference accuracy
plus the quantisation of the HSI48 trim step:

**Reference accuracy contribution**: The USB host SOF timing is accurate to ±250ppm
by specification. The CRS tracks this reference, so the resulting USB clock accuracy
inherits ±250ppm from the reference.

**Trim step quantisation**: The HSI48 trim step is 0.11% to 0.18% (1100-1800 ppm).
After CRS correction, the oscillator is within ±1 trim step of the target, so the
quantisation error is approximately ±900 ppm worst case.

**Combined accuracy**: The total error budget is ±250ppm (reference) plus ±900ppm
(quantisation) = approximately ±1150ppm. This is within the USB requirement of
±2500ppm with 2.2× margin.

ST Application Note AN4879 confirms that crystal-less USB device operation using
the CRS and SOF reference achieves reliable enumeration and sustained operation.
DS13560 Rev 6, Section 3.24 explicitly states: "The synchronization for this
oscillator can be taken from the USB data stream itself (SOF signalization) which
allows crystal-less operation in USB device mode."

### 2.4 The Chicken-and-Egg Problem and Its Solution

A careful reader will notice a circularity: the CRS needs the USB SOF signal to
trim the HSI48, but USB requires the HSI48 to be accurate enough to send and receive
USB packets in the first place. How does the device establish USB communication if
its clock is initially ±3% — well outside USB specification?

The answer lies in USB enumeration behaviour. When a USB device first connects to
a host, the host attempts to communicate at the standard 12 Mbit/s rate. If the
device's clock is off by ±3% (6× the USB specification limit), the initial
communication packets will likely fail — the device may not respond correctly to
the host's setup transactions. However, the USB host retries failed transactions
multiple times before giving up.

The key is that the STM32 receives the first USB SOF packet as soon as the host
detects the device connection (within the first few milliseconds). Even if the
initial clock accuracy is poor and some early packets fail, the CRS begins trimming
immediately from the first received SOF. After 10-20 SOF packets (10-20ms), the
CRS has corrected the HSI48 to within the USB accuracy specification. By the time
the host has completed its initial setup transactions (which take 50-200ms total),
the clock is accurate and stable.

In practice, the STM32G0C1 crystal-less USB implementation is expected to enumerate reliably with
virtually all USB hosts. The ±3% initial accuracy creates a brief window of potential
communication errors immediately after connection, but the CRS trims fast enough
that enumeration completes successfully. This has been validated in production
devices by STMicroelectronics and confirmed by the community.

---

## 3. Clock Configuration for the DSR-1 Module

### 3.1 Two Independent Clocks for Two Independent Functions

The DSR-1 uses two clock domains that must not interfere with each other:

**System clock (64 MHz)**: Drives the Cortex-M0+ core, TIM2 input capture, PWM timer,
ADC, and all peripheral buses. Generated by HSI16 (16 MHz internal RC) multiplied
by the PLL. Must be stable and accurate for servo loop timing.

**USB clock (48 MHz)**: Drives the USB Full Speed PHY exclusively. Generated by
HSI48 trimmed by CRS. Must meet USB accuracy requirements.

These two clocks are completely independent in the STM32G0C1. The USB peripheral
clock is sourced from HSI48 through a dedicated clock path that bypasses the system
PLL entirely. Changes to the system clock (from PLL adjustments, power mode changes,
or dynamic frequency scaling) do not affect the USB clock, and CRS trimming
adjustments to HSI48 do not affect the system clock.

This independence is essential for the servo loop. The TIM2 input capture measures
FG pulse periods in units of system clock ticks (64 MHz, 15.625 ns per tick). If
USB clock trimming could perturb the system clock, it would introduce jitter into
the FG period measurements and degrade servo accuracy. The separate clock
architecture eliminates this coupling entirely.

### 3.2 System Clock Startup Sequence

From power-on, the clock initialisation sequence in `main.c`:

```c
// Step 1: Enable HSI16 and wait for it to be ready
RCC->CR |= RCC_CR_HSION;
while (!(RCC->CR & RCC_CR_HSIRDY));  // Wait ~50µs

// Step 2: Configure PLL: HSI16 × 8 / 2 = 64 MHz
// PLLM = /1, PLLN = ×8, PLLR = /2
RCC->PLLCFGR = RCC_PLLCFGR_PLLSRC_HSI
             | (1 << RCC_PLLCFGR_PLLM_Pos)   // /1
             | (8 << RCC_PLLCFGR_PLLN_Pos)   // ×8 → 128 MHz VCO
             | (2 << RCC_PLLCFGR_PLLR_Pos)   // /2 → 64 MHz
             | RCC_PLLCFGR_PLLREN;            // Enable PLLR output

// Step 3: Enable PLL
RCC->CR |= RCC_CR_PLLON;
while (!(RCC->CR & RCC_CR_PLLRDY));   // Wait ~200µs for PLL lock

// Step 4: Set flash latency for 64 MHz operation (2 wait states)
FLASH->ACR = (2 << FLASH_ACR_LATENCY_Pos) | FLASH_ACR_PRFTEN | FLASH_ACR_ICEN;

// Step 5: Switch system clock to PLL
RCC->CFGR = RCC_CFGR_SW_PLLRCLK;
while ((RCC->CFGR & RCC_CFGR_SWS) != RCC_CFGR_SWS_PLLRCLK);

// System is now running at 64 MHz
// Total time from power-on: approximately 300µs
```

### 3.3 HSI48 and CRS Startup Sequence

The HSI48 and CRS are enabled as part of USB initialisation, which happens after
the system clock is stable:

```c
// Enable HSI48
RCC->CR |= RCC_CR_HSI48ON;
while (!(RCC->CR & RCC_CR_HSI48RDY));  // ~3µs

// Enable CRS peripheral clock
RCC->APBENR1 |= RCC_APBENR1_CRSEN;

// Configure CRS: USB SOF reference, 48000 target count, auto-trim enabled
CRS->CFGR = (47999 << CRS_CFGR_RELOAD_Pos)  // Target: 48000 ticks per SOF
           | (34 << CRS_CFGR_FELIM_Pos)      // Frequency error limit
           | CRS_CFGR_SYNCSRC_USB;           // Use USB SOF as reference

// Enable CRS automatic trimming
CRS->CR = CRS_CR_AUTOTRIMEN | CRS_CR_CEN;

// Configure USB clock source to HSI48
RCC->CCIPR = (3 << RCC_CCIPR_CLK48SEL_Pos); // Select HSI48 for USB
```

The RELOAD value of 47999 corresponds to 48000 - 1, because the counter counts from
RELOAD down to zero (48000 ticks per period). The FELIM value of 34 represents the
frequency error detection threshold in timer counts — approximately 34/48000 =
0.07% frequency error causes a CRS correction event.

After enabling CRS, the HSI48 begins trimming as soon as USB SOF packets arrive.
The CRS interrupt (ESYNCF flag) fires on each SOF, and the automatic trimming
hardware adjusts the HSI48 trim register without software involvement. The entire
USB clock calibration is hardware-automated.

---

## 4. Implications for the DSR-1 Design

### 4.1 Components Eliminated

Removing the external crystal eliminates from the BOM and PCB:

- **Crystal resonator**: Typically 3.2×2.5mm package, 2 pads, ±20-100ppm accuracy,
  approximately $0.15 in quantity
- **Two load capacitors**: Typically 12-18pF 0402 capacitors required by the crystal
  circuit, approximately $0.05 total
- **Crystal routing constraints**: The crystal traces must be short, isolated from
  digital signals, and free from parasitic coupling. On a dense 30×22mm board, these
  routing constraints consume significant PCB real estate

Total savings: approximately $0.20 in components, 2-3mm² of PCB area, and
significant routing effort.

### 4.2 Reliability Improvement

For the WM-D6C application specifically, eliminating the crystal improves Servo Control Board
reliability in two ways relevant to the machine's history and use:

**Mechanical shock immunity**: The WM-D6C is a portable device. It will be carried,
dropped, and subjected to mechanical shock. Quartz crystals are fragile resonating
elements — sharp impacts can crack the crystal blank, causing the oscillator to stop
or shift frequency. An RC oscillator on silicon has no fragile mechanical element
and is immune to mechanical shock.

**Aging immunity**: Quartz crystals age over decades, gradually shifting their
resonant frequency as the crystal structure relaxes from manufacturing stress. This
aging is typically 1-5 ppm per year — small but measurable over the lifetime of a
device. A 30-year-old crystal may have drifted 30-150 ppm from its nominal
frequency. For the servo clock (HSI16/PLL at 64 MHz), this is irrelevant — the
servo calibration accommodates the HSI16's ±1% tolerance. For the USB clock, the
CRS automatically corrects for any HSI48 drift on every SOF packet, making the USB
clock ageless.

### 4.3 The Constraint: USB Must Be Connected for CRS to Work

Crystal-less USB has one operational constraint that a crystal-based design does
not: the CRS needs USB SOF packets to trim HSI48, and SOF packets only arrive when
a USB connection is active.

For the DSR-1, this means:

**USB CDC live tuning**: When a computer is connected and the USB CDC interface is
active, the CRS is receiving SOF packets and the HSI48 is accurately trimmed.
Serial data transfers are reliable.

**DFU firmware update**: When the Servo Control Board is in DFU mode (BOOT0 held, USB-C
connected), the DFU bootloader receives SOF packets and the HSI48 is trimmed.
Firmware updates are reliable.

**No USB connection**: When the Servo Control Board is running the servo loop without a USB
cable connected, the CRS has no reference. HSI48 runs at its untrimmed ±3%
accuracy. This does not matter because the USB peripheral is not used — there is
nothing to clock accurately. The system clock (HSI16/PLL at 64 MHz) is completely
independent of HSI48 and is unaffected.

**Transition moment**: When a USB cable is first connected, the HSI48 begins
untrimmed and the CRS starts trimming from the first SOF. During the first 10-20ms
after connection, USB communication may be unreliable until the CRS brings HSI48
into specification. In practice this is invisible to the user — USB enumeration
takes 50-200ms total, well longer than the CRS convergence time.

### 4.4 Interaction with the Servo Loop

The servo loop runs on the system clock (64 MHz, from HSI16/PLL) and uses TIM2
input capture for FG period measurement. The USB CDC interface runs in the main
loop on the same 64 MHz system clock.

When a USB interrupt fires (SOF received, data available, DFU request), the interrupt
handler preempts the main loop but cannot preempt the TIM2 capture ISR (which is
set to higher priority). The servo loop timing is therefore not affected by USB
activity. The CRS trimming adjustments to HSI48 operate on a completely separate
clock and have zero effect on the 64 MHz system clock used by the servo loop.

This isolation is a deliberate consequence of the two-clock architecture. The servo
loop is shielded from all USB-related activity — clock trimming, interrupt handling,
data transfers — by both hardware architecture and interrupt priority assignment.

---

## 5. Crystal-Less Operation in the Context of a 35-Year-Old Machine

There is a philosophical alignment between crystal-less operation and the DSR-1
project's goals that is worth making explicit.

The WM-D6C's original servo circuit failed partly because its components — the
X701 crystal oscillator, the IC701 divider IC, the CX20084 ASIC — are aging physical
objects. They drift, degrade, and eventually fail. The DSR-1 replaces them with
components that are either more stable (the TARGET_PERIOD integer in flash, the
HSI16/PLL system clock), more self-correcting (the HSI48/CRS combination that
retrains itself on every SOF packet), or more insensitive to aging (the STM32 die,
which will long outlast any quartz crystal).

A crystal on the DSR-1 PCB would be a new fragile component on a board installed in
a decades-old machine that will continue to be handled, carried, and potentially
subjected to mechanical stress for decades to come. Eliminating it removes a future
failure mode before it can be introduced.

The CRS's continuous self-calibration also aligns with the philosophy behind the
servo loop itself: rather than relying on a fixed hardware reference (a crystal),
the system continuously measures reality (SOF packet timing from the USB host) and
corrects itself. This is the same principle as the PI servo loop measuring actual
tape speed through the FG signal and continuously correcting the motor drive. Both
are self-referencing, self-correcting systems — the right approach for a device that
must maintain precision over decades of operation.

---

## 6. Firmware Configuration Summary

For completeness, the complete USB peripheral configuration relevant to crystal-less
operation:

```c
// USB clock: HSI48 trimmed by CRS via USB SOF
// System clock: HSI16 × PLL = 64 MHz (independent of USB clock)

// Enable clocks
RCC->APBENR1 |= RCC_APBENR1_USBEN | RCC_APBENR1_CRSEN;
RCC->CR |= RCC_CR_HSI48ON;
while (!(RCC->CR & RCC_CR_HSI48RDY));

// Set USB clock source to HSI48
RCC->CCIPR = (3 << RCC_CCIPR_CLK48SEL_Pos);

// Configure CRS for USB SOF synchronisation
CRS->CFGR = (47999 << CRS_CFGR_RELOAD_Pos)  // 48000 - 1 ticks per SOF
           | (34   << CRS_CFGR_FELIM_Pos)    // Error limit: ~70ppm
           | CRS_CFGR_SYNCSRC_USB;           // SOF as reference source

// Enable auto-trimming (hardware manages HSI48 trim register automatically)
CRS->CR = CRS_CR_AUTOTRIMEN | CRS_CR_CEN;

// Enable USB peripheral and internal DP pull-up (signals connection to host)
USB->CNTR &= ~USB_CNTR_PDWN;                 // Power down off
// ... additional USB endpoint configuration follows
USB->BCDR |= USB_BCDR_DPPU;                  // Enable DP pull-up = connect to host
```

The CRS runs autonomously after this configuration. No periodic software tasks are
required for clock maintenance.

---

## See Also

- [Digital PLL Servo](digital-pll-servo.md) — how the system clock drives TIM2 and
  the servo loop
- [Why Bare Metal](why-bare-metal.md) — the architecture philosophy that keeps the
  servo loop isolated from USB handling
- [Signal Chain Analysis](signal-chain-analysis.md) — USB data path routing and ESD
  protection
- [Module Datasheet](../design/WMD6C_Module_Datasheet.PDF) — clock configuration
  in Section 3.3

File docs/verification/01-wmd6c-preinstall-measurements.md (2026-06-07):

# WM-D6C Preinstall Measurements

**Project:** DSR-1 / wmd6c-servo  
**File:** `docs/verification/01-wmd6c-preinstall-measurements.md`  
**Status:** Draft / pre-Rev A  
**Scope:** Required documentation and measurements before installing DSR-1 in a Sony WM-D6C / TC-D6C.

---

## 1. Purpose

This document defines the measurements required before DSR-1 is connected to a Sony WM-D6C / TC-D6C.

The goal is to characterize the target machine while it is still as close to original as possible. These measurements establish the safe electrical boundary for DSR-1 and prevent the project from relying on assumptions.

This file must be completed before:

- cutting traces,
- removing IC601,
- removing or bypassing CP304,
- modifying CN301,
- installing a USB-C connector,
- connecting DSR-1 to FG901,
- connecting DSR-1 to the motor-control node,
- or applying power to a DSR-1-connected Sony board.

---

## 2. Safety Position

The target WM-D6C is treated as a rare machine.

Before any modification:

1. Photograph it.
2. Identify it.
3. Inspect it.
4. Measure it.
5. Record raw values.
6. Compare it against the service manual.
7. Only then design or connect the DSR-1 interface.

Do not trust wire colors, prior repairs, internet diagrams, or assumptions from a different board revision.

---

## 3. Measurement Log Location

Create a measurement log for each unit.

Recommended path:

```text
docs/measurements/wm-d6c-serial-72795-preinstall-YYYY-MM-DD.md
```

For other units, replace the serial number.

The log should include:

| Field | Required |
|---|---:|
| Date | Yes |
| Operator | Yes |
| Machine model | Yes |
| Serial number | Yes |
| Board revision | If known |
| Service manual used | Yes |
| Photos taken | Yes |
| Test equipment | Yes |
| Power source | Yes |
| Measurement ground point | Yes |
| Measurement conditions | Yes |
| Raw readings | Yes |
| Interpretation | Yes |
| Open questions | Yes |

---

## 4. Test Unit Identification

### 4.1 Exterior Identification

Record:

| Field | Value |
|---|---|
| Model | Sony WM-D6C |
| Serial number | 72795 |
| Serial-number evidence | Battery-compartment label photo |
| Region/suffix markings | Pending |
| Cosmetic condition | Pending |
| DC jack condition | Pending |
| Battery compartment condition | Pending |
| Prior service evidence | Pending |

### 4.2 Required Exterior Photos

Take clear photos of:

- front face,
- rear face,
- side with controls,
- side with jacks,
- battery compartment,
- serial label,
- CN301 / external DC jack,
- all visible model/suffix markings.

---

## 5. Internal Inspection Photos

Before measuring or removing parts, photograph the internal board.

Required photo set:

| Photo | Purpose |
|---|---|
| Full board overview | Board revision and layout |
| IC601 / CX20084 area | Servo reference |
| IC701 / X701 area | Original reference/timebase |
| CP304 area | Power-support reference |
| CN301 area | External DC input path |
| M901 / motor wiring | Motor and FG reference |
| FG901 area, if visible | FG source |
| Q601 and motor-drive network | Motor-control reference |
| RV601 | Base speed adjustment |
| RV602 | User Speed Tune |
| RV603 | Speed Tune range |
| S601 | Speed Tune switch |
| Battery terminals and rails | Power reference |
| Ground/chassis points | Measurement reference |
| Any prior repair | Compatibility warning |

Photo rules:

- Use good lighting.
- Use macro mode or magnification.
- Take multiple angles if labels are hidden.
- Do not remove parts before photographing them.
- Keep original full-resolution files.

---

## 6. Board / Component Presence Check

Record whether each reference is present and appears original.

| Reference | Present? | Appears original? | Notes |
|---|---:|---:|---|
| IC601 / CX20084 | Pending | Pending | |
| IC701 | Pending | Pending | |
| X701 | Pending | Pending | |
| CP304 | Pending | Pending | |
| CN301 | Pending | Pending | |
| M901 | Pending | Pending | |
| FG901 | Pending | Pending | |
| Q601 | Pending | Pending | |
| Q603 | Pending | Pending | |
| Q604 | Pending | Pending | |
| Q605 | Pending | Pending | |
| RV601 | Pending | Pending | |
| RV602 | Pending | Pending | |
| RV603 | Pending | Pending | |
| S601 | Pending | Pending | |

Document corrosion, lifted pads, replaced parts, missing shields, jumper wires, bodge wires, and cracked solder joints.

---

## 7. Power Source Conditions

Measurements should be repeated under defined power conditions where practical.

### 7.1 Required Power Conditions

| Condition | Required? | Notes |
|---|---:|---|
| Batteries installed | Yes, if safe |
| Regulated external DC supply | Yes |
| Original adapter, if available | Optional |
| USB connected | Only after DSR-1 exists; not for original unit unless applicable |
| Motor running / Play | Yes, for relevant rail tests |
| Stop / idle | Yes |

### 7.2 Regulated Supply Setup

When using external DC:

- use current limiting,
- start at conservative current limit,
- observe polarity,
- document voltage,
- document current limit,
- document actual current draw.

Do not perform wrong-polarity testing on the original unmodified Sony machine unless specifically prepared to risk damage. Fault testing belongs on DSR-1/protection hardware first.

---

## 8. Ground Reference

Before measuring signals, choose and document the ground point.

Record:

| Field | Value |
|---|---|
| Ground point used | Pending |
| Physical location | Pending |
| Reason selected | Pending |
| Probe ground length | Pending |
| Alternate ground points checked | Pending |

Required checks:

- continuity between selected ground and battery negative,
- continuity to chassis where applicable,
- ground noise during Play if possible,
- difference between USB host ground and Sony ground once DSR-1 USB is involved.

Ground choice matters for FG, ADC, USB, and motor measurements.

---

## 9. Power-Path Measurements

### 9.1 CN301 / External DC Input

Measure and record:

| Measurement | Stop | Play | Notes |
|---|---:|---:|---|
| CN301 center contact voltage | Pending | Pending | |
| CN301 sleeve/contact voltage | Pending | Pending | |
| Polarity relative to ground | Pending | Pending | |
| External supply current | Pending | Pending | |
| Voltage sag at motor startup | Pending | Pending | |
| Noise/ripple at input | Pending | Pending | |

Questions to answer:

- Is CN301 original?
- Is polarity as expected?
- Is the jack mechanically reliable?
- Has it been rewired?
- Does external power bypass or interact with battery terminals?
- Does DSR-1 need to retain, replace, or isolate this path?

### 9.2 Battery Rail

Measure:

| Measurement | Stop | Startup | Play | Notes |
|---|---:|---:|---:|---|
| Battery terminal voltage | Pending | Pending | Pending | |
| Rail voltage at board | Pending | Pending | Pending | |
| Current draw | Pending | Pending | Pending | |
| Ripple/noise | Pending | Pending | Pending | |

Questions:

- Does DSR-1 need to support battery operation?
- What is the lowest expected rail voltage?
- Is there a surge during motor startup?
- Does the rail remain stable during Play?

### 9.3 CP304 / Power-Support Circuit

Measure if safely accessible:

| Measurement | Stop | Startup | Play | Notes |
|---|---:|---:|---:|---|
| CP304 input voltage | Pending | Pending | Pending | |
| CP304 output voltage | Pending | Pending | Pending | |
| Ripple/noise | Pending | Pending | Pending | |
| Current estimate | Pending | Pending | Pending | |
| Temperature after operation | Pending | Pending | Pending | |

Questions:

- Is CP304 functional?
- Does DSR-1 replace CP304 or only replace part of its role?
- What rail does CP304 provide?
- What load does that rail support?
- Does CP304 behavior differ between battery and external power?

---

## 10. Servo / FG Measurements

### 10.1 FG901 Waveform

Measure at the FG signal point before connecting DSR-1.

Record:

| Measurement | Value |
|---|---:|
| Probe point | Pending |
| Ground point | Pending |
| Tape state | Pending |
| Power source | Pending |
| FG waveform high voltage | Pending |
| FG waveform low voltage | Pending |
| DC offset | Pending |
| Peak-to-peak voltage | Pending |
| Frequency at nominal speed | Pending |
| Period at nominal speed | Pending |
| Edge rise/fall behavior | Pending |
| Noise/ringing | Pending |
| Behavior during startup | Pending |
| Behavior during stop | Pending |

Required captures:

- Stop / no FG.
- Motor startup.
- Steady Play.
- Speed Tune off.
- Speed Tune on, if safe.
- Different power modes, if practical.

Questions:

- Is FG safe for direct STM32 input?
- Does it require division, clamping, buffering, comparator, or Schmitt conditioning?
- Is the waveform clean enough for timer capture?
- What is the true target period at correct speed?

### 10.2 Audio Speed Reference

If a calibrated test tape is available:

| Measurement | Value |
|---|---:|
| Test tape type | Pending |
| Expected tone frequency | Pending |
| Measured output frequency | Pending |
| Power source | Pending |
| Speed Tune state | Pending |
| RV601 position | Pending |
| FG frequency at same time | Pending |

This ties FG target to actual tape speed.

---

## 11. Motor-Control Measurements

### 11.1 Q601 / Motor-Control Node

Before connecting DSR-1 output, measure the original control behavior.

Record:

| Measurement | Stop | Startup | Play | Notes |
|---|---:|---:|---:|---|
| Control node voltage | Pending | Pending | Pending | |
| Motor terminal voltage | Pending | Pending | Pending | |
| Motor current estimate | Pending | Pending | Pending | |
| Response to load/tape | Pending | Pending | Pending | |
| Output ripple/noise | Pending | Pending | Pending | |

Questions:

- What voltage range must DSR-1 reproduce?
- Is the control node above the STM32's safe direct-drive range?
- Does the node expect voltage drive, current drive, or high impedance?
- What is the safe inactive state?
- What happens during Stop?
- What happens during motor startup?

### 11.2 Motor Startup Current

If safely measurable:

| Measurement | Value |
|---|---:|
| Peak startup current | Pending |
| Steady play current | Pending |
| Power source | Pending |
| Tape loaded? | Pending |
| Duration of surge | Pending |

This determines protection, regulators, PD current requirements, and safe output staging.

---

## 12. Speed-Control Network Measurements

### 12.1 RV601 — Base Speed Adjustment

Measure:

| Measurement | Value |
|---|---:|
| Wiper min voltage | Pending |
| Wiper max voltage | Pending |
| Wiper nominal voltage | Pending |
| Supply/reference side voltage | Pending |
| Ground/reference side voltage | Pending |
| Source impedance estimate | Pending |
| Noise while motor running | Pending |

Questions:

- Is RV601 safe for STM32 ADC?
- Does it need scaling?
- What firmware midpoint should be used?
- Is RV601 factory-set or accessible?

### 12.2 RV602 — User Speed Tune

Measure:

| Measurement | S601 off | S601 on | Notes |
|---|---:|---:|---|
| Wiper min voltage | Pending | Pending | |
| Wiper max voltage | Pending | Pending | |
| Center/nominal voltage | Pending | Pending | |
| Effective behavior | Pending | Pending | |

Questions:

- Does RV602 electrically disconnect when S601 is off?
- Is its range ADC-safe?
- Does it have a center detent?
- How much speed change does it command in the original system?

### 12.3 RV603 — Speed Tune Range

Measure:

| Measurement | Value |
|---|---:|
| Wiper min voltage | Pending |
| Wiper max voltage | Pending |
| Nominal position voltage | Pending |
| Interaction with RV602 | Pending |
| ADC safety | Pending |

Questions:

- Is RV603 a factory range trim?
- Does it scale RV602 directly?
- What firmware scaling range should correspond to the original behavior?

### 12.4 S601 — Speed Tune Switch

Measure:

| Measurement | Value |
|---|---:|
| Voltage when off | Pending |
| Voltage when on | Pending |
| Active polarity | Pending |
| Pull-up/pull-down behavior | Pending |
| Contact bounce observed? | Pending |
| Interaction with RV602 | Pending |

Questions:

- Should firmware read S601 directly?
- Is external debounce/filtering needed?
- Is the signal safe for GPIO input?

---

## 13. Original Timebase / Reference Measurements

Document the original quartz/reference area before removing or bypassing anything.

| Reference | Measurement / observation | Status |
|---|---|---|
| X701 | Presence and condition | Pending |
| IC701 | Presence and condition | Pending |
| Reference waveform | Frequency / amplitude if safely measurable | Pending |
| Relation to servo circuit | Schematic comparison | Pending |

Questions:

- Can DSR-1 retain or sample the original reference?
- Does the original reference still operate?
- Is it safer/easier to add an independent external reference?
- Does retaining original reference improve preservation value?

---

## 14. USB-C Mechanical Preinstall Survey

Before deciding USB-C placement, document the case and internal clearance.

Required photos/notes:

| Area | Purpose |
|---|---|
| Existing CN301 opening | Possible replacement/alternate location |
| Side panel clearance | USB-C connector/cable clearance |
| Internal cavity near CP304 | Board placement |
| Battery compartment clearance | Avoid interference |
| Shell thickness | Connector mounting |
| Nearby controls/switches | Avoid obstruction |
| Cable insertion angle | User access |

Questions:

- Does USB-C replace CN301 or coexist with it?
- Is case modification acceptable?
- Can a USB-C cable be inserted without stressing the PCB?
- Does connector placement block batteries or controls?
- Does USB-C placement expose the board to mechanical damage?
- Is a panel-mount connector or short internal harness better than PCB-mounted USB-C?

---

## 15. USB Ground / Noise Preinstall Considerations

USB cannot be fully tested until DSR-1 exists, but original ground behavior can be measured.

Before installation:

- identify chassis ground,
- identify main board signal ground,
- identify motor return path,
- identify battery negative path,
- measure continuity between them,
- observe ground noise during Play if possible.

Record:

| Measurement | Value |
|---|---:|
| Battery negative to selected ground | Pending |
| Selected ground to chassis | Pending |
| Motor return to selected ground | Pending |
| Ground noise during Play | Pending |
| Ground noise during motor startup | Pending |

These values inform USB shield and ground strategy.

---

## 16. Preinstall Acceptance Checklist

DSR-1 may not be connected until the following are complete.

| Requirement | Status |
|---|---|
| Serial number recorded | Done: 72795 |
| Exterior photos taken | Pending |
| Internal board photos taken | Pending |
| Board revision identified or marked unknown | Pending |
| IC601 area documented | Pending |
| CP304 area documented | Pending |
| CN301 area documented | Pending |
| FG901/M901 area documented | Pending |
| Q601/motor-control area documented | Pending |
| RV601/RV602/RV603 documented | Pending |
| S601 documented | Pending |
| Power rails measured | Pending |
| FG waveform measured | Pending |
| Motor-control node measured | Pending |
| Speed-control voltages measured | Pending |
| S601 logic measured | Pending |
| Original timebase/reference documented | Pending |
| USB-C mechanical survey complete | Pending |
| Ground reference selected | Pending |
| Measurement log committed | Pending |

---

## 17. Abort Conditions

Stop measurement or installation immediately if:

- the board revision does not match the assumed reference,
- prior repairs make the circuit ambiguous,
- CN301 has been rewired,
- CP304 is missing or modified,
- FG signal exceeds safe probe/interface expectations,
- motor-control voltage is outside expected range,
- rail current is abnormally high,
- power supply current limit is hit unexpectedly,
- smoke, odor, heat, or audible distress occurs,
- mechanical disassembly risks damage.

Document the condition before proceeding.

---

## 18. Output of This Procedure

Completing this procedure should produce:

1. A unit measurement log.
2. Full exterior and interior photos.
3. Confirmed board/revision notes.
4. FG waveform captures.
5. Motor-control measurements.
6. Speed-control measurements.
7. Power-path measurements.
8. USB-C mechanical feasibility notes.
9. Grounding notes.
10. A list of safe DSR-1 connection points.
11. A list of open questions for schematic revision.

Only after those outputs exist should DSR-1 installation planning continue.

---

## 19. Final Rule

The Sony unit is the reference artifact. Do not modify it to fit the theory.

Modify the DSR-1 design to fit the measured machine.

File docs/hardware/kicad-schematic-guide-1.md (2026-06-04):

# DSR-1 KiCad 10 Schematic Implementation Guide

**Project:** WM-D6C Capstan Servo Replacement Module (DSR-1)
**Tool:** KiCad 10.x
**Scope:** Complete schematic entry instructions, sheet by sheet

> This document is the working guide for translating the DSR-1 design into a
> KiCad 10 schematic. Read each zone before drawing it. The signal
> chain analysis, interface contract, and power architecture documents are the
> authoritative sources for all component values — this document tells you *how*
> to enter them in KiCad, not *why* they are what they are.
>
> **Structure:** the design is one flat **D-size** sheet — no hierarchy, no sub-sheets.
> The KiCad project's sheet is already a single D page; its component set is still the
> pre-battery design (AP63203, no charger), so the battery / charge / indicator entries
> here are changes to apply.

---

## Compatibility Scope

DSR-1 targets the full WM-D6C / TC-D6C production run (1984–2002). Two distinct
servo circuit families exist across that run:

| Family | Servo IC | Motor drive | Years (approx.) | Governing manual |
|---|---|---|---|---|
| **Ver. 1.0** (primary) | CX20084 | Single Q601 (2SB1013 PNP) | 1984–mid 2001 | `fb4872.pdf` |
| **Ver. 1.1** (planned variant) | CX-069A | Q601–Q605 (five transistors) | mid 2001–2002 | `sony_wm-d6c_tc-d6c_ver-1.1.pdf` |

**Rev A targets Ver. 1.0 boards.** This covers the majority of surviving units.
CX-069A board support is planned as a separate variant and is out of scope for
Rev A schematic capture.

Within Ver. 1.0, there are two PCB construction generations:

| Sub-generation | Approx. years | Construction |
|---|---|---|
| Early through-hole | 1984–~1994 | Through-hole PCB |
| Later SMD | ~1994–2001 | SMD main board |

Both sub-generations have the same CX20084-based servo circuit and the same DSR-1
electrical interface. The difference is mechanical — harness routing and connector
placement. The DSR-1 board does not change; installation harness documentation
covers both sub-generations.

**To identify board family before installation:** open the machine and read the
IC at position IC601. CX20084 = Ver. 1.0 (proceed with this guide). CX-069A =
Ver. 1.1 (do not install Rev A; wait for Ver. 1.1 variant documentation).

---

## Prerequisites

Before opening KiCad:

1. `.gitignore` is committed (excludes `*-backups/`, `fp-info-cache`, `*.lock`,
   `*_autosave.*`)
2. `hardware/datasheets/` contains `stm32g0b1cc.pdf` (DS13560 Rev 6), `mt3608.pdf`,
   `fb4872.pdf`, and `sony_wm-d6c_tc-d6c_ver-1.1.pdf`
3. The `DSR-1.kicad_sym` project symbol library has been created and registered
   under Project scope in Preferences → Manage Symbol Libraries
4. Custom power symbols `B+1` and `B+3` have been created in `DSR-1.kicad_sym`
   with pin type **Power input**, pin number and name hidden, flagpole graphic body
5. Page size set to **D** (File → Page Settings → Page size **D**) — the whole design is one flat sheet

---

## KiCad Shortcut Reference

| Action | Shortcut |
|---|---|
| Add symbol | `A` |
| Add wire | `W` |
| Add net label | `L` |
| Add power port | `P` |
| Mirror horizontal | `X` |
| Mirror vertical | `Y` |
| Edit properties | `E` |
| Run ERC | Inspect → Electrical Rules Checker |
| Add no-connect flag | `Q` |

---

## Single-Sheet Layout (D-size)

The DSR-1 schematic is a **single flat sheet** on a **D-size** page (File → Page
Settings → Page size **D**). There is no hierarchy, no root sheet, and no sub-sheet
pins — the whole design (~90 components) fits on one D-sheet with headroom for the
future Ver. 1.1 / CX-069A variant.

Organize the canvas into four visual **zones**, left-to-right by signal flow. Zones are
just regions (optionally boxed with a graphic rectangle + text label); they carry no
electrical meaning:

```
┌─ Power ─────────────┐ ┌─ Microcontroller ─┐ ┌─ Signal Conditioning ─┐ ┌─ Connectors ─┐
│ USB-C / barrel in   │ │ STM32G0C1KCU6     │ │ FG divider + clamp    │ │ J1 harness   │
│ CN3058E charge +    │ │ decoupling, boot, │ │ NPN motor drive       │ │ J2 SWD       │
│ LiFePO4 power-path  │ │ pin assignments   │ │ ADC clamps            │ │ J3 LED board │
│ TPS63070 B+1        │ │                   │ │ VBAT sense divider    │ │ test pads    │
│ MT3608 B+3, MCP1700 │ │                   │ │                       │ │              │
└─────────────────────┘ └───────────────────┘ └───────────────────────┘ └──────────────┘
```

The sections below are written per zone. Component values come from the design docs
(signal-chain analysis, interface contract, power-supply design); this guide tells you
how to enter them.

---

## Net Labeling

On a single sheet, connectivity is trivial — **a net label connects to every identical
label anywhere on the sheet.** There are no hierarchical labels, sheet pins, or global
labels to manage (those exist only to cross sheet boundaries).

- **Net labels (`L`)** — name any net you want to join by name instead of a drawn wire
  (`FG_IN`, `MOTOR_PWM`, `VBAT_SENSE`, `BATT_LED1`, …). Same name = same net. Use them
  to avoid long cross-zone wires.
- **Power symbols (`P`)** — `B+1`, `B+3`, `+3V3`, `GND` connect globally by symbol.
  Place a PWR_FLAG at each rail's source so ERC sees it driven.
- **Local wiring** — short within-zone nets can just be wires; reserve labels for
  signals that cross zones.

Every net is traceable end-to-end with no import/export step — which removes the most
common ERC pitfall of the old hierarchical layout ("net has no driver / not imported").

---

## Power Zone

**Purpose:** The entire power chain on one region of the sheet, in signal-flow
sub-zones: **(A)** input — USB-C and/or barrel; **(B)** charge, battery, and power-path
(battery-integrated build); **(C)** the TPS63070 B+1 buck-boost; and **(D)** B+3
(MT3608) and 3.3V (MCP1700). Three builds share this zone, differentiated by DNP: the
**battery-integrated build (primary)**, **Variant A** (wall, USB-C 9V PD, no cells),
and **Variant B** (wall, barrel, no cells).

> **Authoritative values:** `power-supply-design.md` §5.2 (TPS63070) and §7.1–§7.7
> (cell, charger, power-path, protection, indicator). This guide tells you how to enter
> them in KiCad.
>
> **⚠ KiCad is behind the design.** The committed project still shows U3 = AP63203WU-7
> (a fixed buck) and no battery. The entries below are the intended design — the
> AP63203 is **replaced** by the TPS63070 (sub-zone C) and the battery front end
> (sub-zone B) is added. Treat sub-zones B and C as the changes to apply.

---

### A. Input

**J_USB — USB-C mid-mount receptacle** (battery build + Variant A; DNP for Variant B)

- Symbol: search `USB_C` in the KiCad Connector library or use a custom symbol.
- VBUS → `VBUS` net (feeds the CN3058E charger at 5V in the battery build) and, in
  Variant A, the IP2721 input.
- D+/D− → `USB_DP_RAW`, `USB_DM_RAW`; CC1, CC2 → `CC1`, `CC2`; GND/Shield → GND.

**U1 — IP2721 USB PD Trigger (TSSOP-16)** — Variant A only

- Pins VIN, VBUSG, VBUS, CC1, CC2, SEL, GND. VIN (P$2) and VBUSG (P$1) → VBUS (tie
  together). VBUS (P$16) → `9V_PD` after successful negotiation. CC1/CC2 → `CC1`/`CC2`.
  SEL (P$11) → configure for a 9V request. C1 4.7µF 16V X5R VBUS→GND.
- **DNP on the battery build and Variant B.** In the battery build a 9V contract would
  over-volt the CN3058E charger (6V VIN max) — the battery build stays at 5V.

> **VBUSG note:** VBUSG is the internal pass-element gate drive and must be tied to VIN;
> floating it prevents `9V_PD` from becoming valid after negotiation.

**ESD — USBLC6-2SC6Y (SOT-23-6)**

- I/O1 → `USB_DM_RAW`; I/O2 → `USB_DP_RAW`; GND → GND; VCC → `+3V3`.
- Outputs `USB_DM`, `USB_DP` → the Microcontroller zone.

**Variant B — barrel jack, polarity-agnostic** (DNP for battery build and Variant A)

> Variant B accepts 9V DC via a 5.5mm/2.1mm barrel jack with **no assumed polarity** —
> a Schottky bridge guarantees correct output polarity regardless of adapter wiring,
> eliminating the original CN301 centre-negative failure mode.

- **J2** barrel jack: both pins feed the bridge (no polarity). 9V DC, ≥500mA adapter.
- **Bridge D2–D5 (SS14, SOD-123):**

```
         D2               D3
tip ───►|──┬─── DC+ ───────┬──|◄─── sleeve
           │               │
        (left AC)       (right AC)
           │               │
tip ───|◄──┴───────────────┴──►|─── sleeve
         D4               D5
                   │
                  GND
```

- DC+ (D2,D3 cathodes) → **F1** (polyfuse 500mA hold / 1.5A trip, 0805) → `B+1_RAW`;
  GND (D4,D5 anodes) → GND; DC+ ≈ 8.2V at load.
- **D6** SMBJ12A-13-F TVS (SMA): cathode → `B+1_RAW` (after F1), anode → GND. 12V
  standoff, 19.9V max clamp — under the regulator VIN max.

---

### B. Charge, Battery & Power-Path (battery-integrated build)

**BT1 — 1S4P LiFePO4 pack (4× IFR14500)**

- 2-pin to the cell holder: `VBAT+` → `VBAT` (via protection), `VBAT−` → GND.
- 3.2V nominal, 3.6V float, ~2.4–2.8Ah.
- Schematic note: `⚠ Parallel user-removable cells: a reversed insertion reverse-charges
  the others. Use an orientation-keyed holder or soldered cells; a series polyfuse limits
  fault current. See power-supply-design.md §7.1.`

**U_PROT — 1S LFP protection (HY2112-CB + dual N-FET)**

- HY2112-CB (over-charge ~3.75V, over-discharge ~2.0–2.4V) + dual N-FET (FS8205-class)
  in series between the pack and the `VBAT` node.
- Schematic note: `Use the LFP-specific HY2112-CB — NOT a DW01 (its 4.25V/2.4V Li-ion
  thresholds never protect a 3.6V LFP cell). See §7.5.`

**U_CHG — CN3058E LiFePO4 charger (eSOP-8)**

| CN3058E pin | Connection |
|---|---|
| VIN | `VBUS` (5V) + 1µF to GND |
| BAT | `VBAT` + C_BAT 4.7–10µF to GND (loop stability) |
| ISET | R_ISET 2.0kΩ to GND → I_CHG = 1.218 / 2000 ≈ 0.6A (0.25C) |
| TEMP | GND (NTC disabled) |
| CHRG, DONE | open-drain → LED + series R to VIN; optionally to `CHRG_SENSE`/`DONE_SENSE` |
| GND / thermal pad | GND, copper pour |

- Schematic note: `Linear charger dissipates (VIN−VBAT)·I_CHG ≈ 0.84W at 0.6A; folds
  above ~600mA. 5V VBUS only — 9V exceeds the 6V VIN max. See §7.2.`

**Power-path — load-sharing P-FET**

```
   VBUS ──[D1: ideal-diode P-FET (or SS34 Schottky)]──┬────────────► V_SYS ──► TPS63070 VINx
                                                       │
   VBUS ──[D2: small Schottky]──┬──────► Q_PP gate     │
                                │                       │
   VBAT ── source ┐          [R_G 100k]                 │
                 Q_PP (PMOS)    │                       │
   V_SYS ◄─ drain ┘            GND ──── (battery feeds V_SYS when USB absent)
```

- Q_PP PMOS: source `VBAT`, drain `V_SYS`. USB present → gate to VBUS via D2 → **off**
  (battery isolated, charger sees a clean cell). USB absent → R_G to GND → **on**.
- D1: prefer an ideal-diode P-FET (`V_SYS` ≈ 4.9V); SS34 Schottky is the simple fallback
  (≈ 4.6V). Also blocks back-feed into VBUS.

---

### C. B+1 Regulator — TPS63070 Buck-Boost

The single B+1 regulator in every build. It **replaces the AP63203 buck** so one part
covers all inputs: it boosts when `V_SYS`/VBUS is below 6V (battery and 5V cases) and
bucks the 9V Variant A case.

| TPS63070 pin | Connection |
|---|---|
| VINA / VINB | `V_SYS` (battery) or `9V_PD`/bridge (wall) + 10µF input cap to GND |
| VOUT | `B+1` node, 6.0V + bulk output cap to GND |
| FB | R1 (649kΩ) from `B+1` / R2 (100kΩ) to GND |
| L1, L2 | inductor **between the two switch pins** (not SW→VOUT), 1.5µH class, ≥3.6A sat |
| EN | RC soft-start to `V_SYS`; **do not float** (0.8V threshold) |
| PS/SYNC, PG | per datasheet |
| GND / PGND / thermal pad | GND + via array |

- Vref 0.8V; 0.8 × (1 + 649/100) = 5.99V ✓ (PWR_FLAG on `B+1`).
- 3.6A switch limit; ~1.6A input at the 2.8V pack floor.
- Schematic note: `Buck-boost inductor sits between L1 and L2 — different routing from
  the AP63203 buck. See power-supply-design.md §5.2.`

---

### D. B+3 (10.8V) and 3.3V Generation

Downstream of the `B+1` node; present in every build.

**U_BOOST — MT3608 Boost (SOT-23-6), 6V → 10.8V**

| MT3608 pin | Connection |
|---|---|
| VIN | `B+1` + 10µF input cap to GND |
| GND | GND |
| SW | L_BOOST (4.7µH, CDRH4D28) → D_BOOST anode |
| EN | `B+1` (always-on) |
| FB | R_UPPER (169kΩ) / R_LOWER (10kΩ) junction |
| (implicit) | D_BOOST cathode = VOUT = `B+3` |

- VOUT = 0.6 × (1 + 169/10) = 10.74V ✓. D_BOOST = SS14 (SMA).
- C_BOOST_IN 10µF 10V X5R; **C_BOOST_OUT 47µF 16V X5R** (not 22µF — DC-bias derating).
- PWR_FLAG on `B+3`.
- Schematic note: `SW node high dV/dt at 1.2 MHz — trace <3mm; ≥2mm clearance to all
  FG/ADC/DAC traces.`

**U_LDO — MCP1700T-3302E/TT LDO (SOT-23-3), 6V → 3.3V**

- VIN → `B+1`; VOUT → `+3V3`; GND → GND.
- C_LDO_IN / C_LDO_OUT: 1µF 10V X5R (0402) + 10µF 10V X5R (0805) each. PWR_FLAG on `+3V3`.

---

### Build matrix & DNP

| Component | Battery-integrated | Variant A (wall) | Variant B (wall) |
|---|---|---|---|
| U3 TPS63070 buck-boost (B+1) | Populate | Populate | Populate |
| AP63203WU-7 | — superseded | — superseded | — superseded |
| J_USB USB-C receptacle | Populate (5V) | Populate (9V PD) | DNP |
| U1 IP2721 PD trigger | **DNP** (9V over-volts charger) | Populate | DNP |
| D1 USBLC6 ESD | Populate | Populate | DNP |
| J2 barrel + D2–D5 + F1 + D6 TVS | DNP | DNP | Populate |
| BT1 pack, U_PROT, U_CHG, Q_PP, D1/D2 power-path | Populate | DNP | DNP |
| U_BOOST MT3608, U_LDO MCP1700 | Populate | Populate | Populate |

---

### Net labels used in this zone

- `VBUS` — USB 5V in (charger + power-path)
- `9V_PD` — Variant A only (IP2721 → TPS63070 VIN)
- `B+1_RAW` — Variant B bridge output → TPS63070 VIN
- `V_SYS` — power-path output → TPS63070 VIN (battery build); local
- `VBAT` — pack / protection node (charger BAT, power-path, sense-divider tap); local
- `USB_DP`, `USB_DM`, `CC1`, `CC2` → the Microcontroller zone
- `CHRG_SENSE`, `DONE_SENSE` → the Microcontroller zone (optional, battery build)

---

## Microcontroller Zone (STM32G0C1)

**Purpose:** STM32G0C1KCU6 and all support components. Place the STM32 in the
centre and work outward.

### U1 — STM32G0C1KCU6 (UFQFPN32)

Use the KiCad `MCU_ST_STM32G0` library symbol `STM32G0C1KCUx`, copied to
`DSR-1.kicad_sym` and renamed `STM32G0C1KCU6`. The UFQFPN-32 package has
**1 VDD and 1 VSS** in the 32-pin K package. VDD and VDDA share one pin;
VSS and VSSA share one pin. Expose the thermal pad (EP) as described below.

> **⚠ Verify VDDIO2 against STM32G0C1 datasheet.** The G0B1 GP variant had no
> separate VDDIO2 pin. The G0C1 may differ — confirm in the STM32G0C1 UFQFPN-32
> pinout table. If a separate VDDIO2 pin is present, add 100nF X5R 0402 +
> 4.7µF X5R 0402 decoupling to `+3V3` and update this guide.

**UFQFPN-32 GP (_KxU) confirmed pin map — DS13564 Rev 5:**

| Pin | Name | DSR-1 assignment |
|-----|---|---|
| 1 | PB9 | No-connect |
| 2 | PC14-OSC32_IN | No-connect |
| 3 | PC15-OSC32_OUT | No-connect |
| 4 | VDD/VDDA | `+3V3` (combined) |
| 5 | VSS/VSSA | GND (combined) |
| 6 | PF2-NRST | Reset — 100nF to GND |
| 7 | PA0 | `FG_IN` / TIM2_CH1 |
| 8 | PA1 | `RV601_WIPER` / ADC_IN1 |
| 9 | PA2 | `RV602_WIPER` / ADC_IN2 |
| 10 | PA3 | `RV603_WIPER` / ADC_IN3 |
| 11 | PA4 | No-connect (DAC1_OUT1 — not used, see note) |
| 12 | PA5 | `MOTOR_EN_MON` / GPIO |
| 13 | PA6 | `MOTOR_PWM` / TIM3_CH1 |
| 14 | PA7 | `SPEED_TUNE_SW` / GPIO |
| 15 | PB0 | `VBAT_SENSE` / ADC_IN8 (battery) |
| 16 | PB1 | `VBAT_SENSE_EN` / GPIO sense-gate (battery) |
| 17 | PB2 | `BATT_LED1` / GPIO·TIM (battery) |
| 18 | PA8 | `CC1` / UCPD1_CC1, UCPD1_DBCC1 |
| 19 | PA9 | `CC2` / UCPD1_CC2 |
| 20 | PC6 | `S801_BATT` / GPIO in (battery) |
| 21 | PA10 | No-connect / spare |
| 22 | PA11 [PA9] | `USB_DM` |
| 23 | PA12 [PA10] | `USB_DP` |
| 24 | PA13 | `SWDIO` |
| 25 | PA14-BOOT0 | `SWDCLK` |
| 26 | PA15 | `BATT_LED2` / GPIO·TIM (battery) |
| 27 | PB3 | `BATT_LED3` / GPIO·TIM (battery) |
| 28 | PB4 | `BATT_LED4` / GPIO·TIM (battery) |
| 29 | PB5 | `BATT_LED5` / GPIO·TIM (battery) |
| 30 | PB6 | `DEBUG_TX` / USART1_TX |
| 31 | PB7 | `CHRG_SENSE` / GPIO in (optional) |
| 32 | PB8 | `DONE_SENSE` / GPIO in (optional) |
| EP | VSS | GND — expose this pin in Symbol Editor; via array in layout |

> **PB15 does not exist in the GP variant** (_KxU). PB15 is only present in
> the N variant (_KxUxN). The previous guide entry "PB15 / UCPD1_CC2" was
> wrong. CC2 → PA9 (pin 19) for UCPD1_CC2.
>
> **DEBUG_TX moved from PA9 to PB6.** PA9 is required for UCPD1_CC2 and cannot
> simultaneously serve USART1_TX. PB6 (pin 30) carries USART1_TX and is
> available.
>
> **VDDIO2 confirmed absent** in GP variant. Pin 20 = PC6. No VDDIO2 decoupling
> needed. (DS13564 Figure 4, GP version _KxU confirmed.)

> **PA4 (DAC1_OUT1) is not used for motor drive.** Q601 (2SB1013 PNP) on
> Ver. 1.0 boards has its emitter at B+3 (10.8V); the base operating range
> exceeds the 3.3V DAC output range. Motor drive uses TIM3 PWM on PA6 through
> the NPN level-shift stage on the Signal Conditioning zone. PA4 may be left unconnected with a
> no-connect flag or reserved as a spare ADC/DAC pin.

**Unused pins:** Place a No-Connect flag (`Q`) on every unused GPIO pin.

---

> **Battery-build pins:** pins 15–17, 20, 26–29, and 31–32 carry the battery level
> indicator and charge-status signals (No-connect on wall-only builds). LED segment
> pins on timer channels can PWM-dim the bar (night dimming, charge animation); plain
> GPIO gives on/off segments. Reconcile with `stm32g0b1-pin-allocation.md`.

### Decoupling Network

**VDD/VDDA decoupling (pin 4 — combined supply in 32-pin package):**
- 100nF 10V X5R 0402 — power supply decoupling
- 100nF 10V C0G 0402 — analog noise filtering (C0G/NP0, lower noise than X5R)
- 1µF 10V X5R 0402 — bulk bypass

All three caps connect between pin 4 and GND. The C0G cap should be placed
closest to the pin on the PCB as it serves the ADC inputs.

> **VDDIO2:** Verify whether the STM32G0C1KCU6 UFQFPN-32 exposes VDDIO2 as a
> separate pin. If present, add 100nF X5R 0402 + 4.7µF X5R 0402 between
> VDDIO2 and GND. If absent (combined with VDD), no additional decoupling needed.

All capacitor GND terminals connect directly to the nearest GND power symbol.

---

### Boot and Reset

**BOOT0 (PA14-BOOT0 — shared with SWDCLK):**

```
+3V3 ──[10kΩ]────┬── BOOT0
                  │
                 GND (holds BOOT0 low = normal boot from flash)
```

**NRST:**
- 100nF to GND; no external reset button on Rev A unless space allows
- Add no-connect flag if not bringing out to a test point

---

### Net labels used in this zone

**Inputs:**
- `USB_DP`, `USB_DM`, `CC1`, `CC2` ← the Power zone
- `FG_IN`, `RV601_WIPER`, `RV602_WIPER`, `RV603_WIPER`, `MOTOR_EN_MON` ← the Signal Conditioning zone
- `SPEED_TUNE_SW`, `SWDIO`, `SWDCLK` ← the Connectors zone

**Outputs:**
- `MOTOR_PWM` → the Signal Conditioning zone

**Battery build:**
- Inputs: `VBAT_SENSE`, `S801_BATT`, `CHRG_SENSE`, `DONE_SENSE`
- Outputs: `VBAT_SENSE_EN`, `BATT_LED1`…`BATT_LED5`

---

## Signal Conditioning Zone

**Purpose:** Every analog interface between the STM32 and the machine. Conditions
incoming machine-voltage signals down to 3.3V; level-shifts STM32 PWM output up
to drive the machine's motor transistor.

### FG Signal Path (J1 Pin 1 → PA0)

FG901 GP2S22AB is an open-collector optical interrupter. Its output is pulled to
B+1 (~6V) through a resistor on the WM-D6C main board. The swing is approximately
0 to 5.9V — exceeding the STM32's 3.6V absolute maximum input.

```
FG_RAW (from the Connectors zone, J1 pin 1)
    │
   [R3: 10kΩ 1% 0402]
    │
   [R4: 22kΩ 1% 0402] ──── GND        ← voltage divider lower leg
    │
   ├──[D_FG1: BAT54, anode→node, cathode→+3V3]   ← high-side clamp
   ├──[D_FG2: BAT54, anode→GND, cathode→node]    ← low-side clamp
   │
   [C7: 10pF C0G 0402] ──── GND        ← motor-brush noise filter
    │
   FG_IN (net label → the Microcontroller zone, PA0)
```

Divider math: V_node = V_FG × 22/(10+22) = V_FG × 0.6875
At 5.9V swing: 5.9 × 0.6875 = 4.06V → BAT54 clamps to ≤3.6V ✓

Schematic note: `⚠ VERIFY ACTUAL FG SWING ON BENCH BEFORE POWER-ON.
R4 value may need adjustment based on measured B+1 and pull-up resistor.
See signal-chain-analysis.md §1 for formula. Do not connect FG directly
to PA0 without confirming the conditioned voltage is below 3.3V.`

---

### Motor Drive Output (PA6 → J1 Pin 2 → Q601 base)

Q601 on WM-D6C Ver. 1.0 boards is a **2SB1013 PNP transistor** with emitter at
B+3 (10.8V). The base must be pulled well below the emitter to turn it on. The
STM32 3.3V PWM output cannot drive this base directly — a level-shift stage
using a small-signal NPN (Q_LS) is required.

**Boot-safe behavior:** At reset, TIM3 PWM defaults to 0% duty cycle. Q_LS is
off. R9 pulls Q601's base toward B+1 (6V). Vbe = 6V − 10.8V = −4.8V — Q601
is firmly off. Motor cannot run uncontrolled during boot or firmware update.

```
MOTOR_PWM (from the Microcontroller zone, PA6 TIM3_CH1, 15.6 kHz)
    │
   [R7: 1kΩ 5% 0402]
    │
    ├──[C8: 100nF 10V X5R 0402] ──── GND    ← PWM-to-analog RC filter
    │                                          fc = 1/(2π×1kΩ×100nF) = 1.59 kHz
    │
   Q_LS base (MMBT3904 NPN, SOT-23)
   Q_LS emitter → GND
   Q_LS collector
    │
   [R8: 10kΩ 5% 0402] ──── [Q601_BASE net / J1 pin 2]
    │
   [R9: 100kΩ 5% 0402] ──── B+1 power symbol
    │
   Q601_BASE (net label → the Connectors zone, J1 pin 2)
```

Q_LS is the MMBT3904 NPN on the DSR-1 board. Q601 (2SB1013) is on the WM-D6C
main board — use a generic PNP symbol with value `2SB1013` and note `Off-board`.

Schematic note: `Q601 (2SB1013 PNP) is on WM-D6C main board — NOT on DSR-1 PCB.
Q601 emitter → B+3 via Q703/Q704 mode-switch chain. Q601 base operating range
must be measured on bench to confirm R9 sizing. See signal-chain-analysis.md §2.`

---

### Motor Enable Monitor (J1 Pin 3 → PA5)

The MOTOR_EN signal at the IC601 footprint pin 7 pad is held HIGH (~4.4V) during
playback via R605 (pullup to B+1). Q702 on the auto-off board pulls it LOW at
end-of-tape or auto-off. After IC601 is removed, this signal is accessible at
the IC601 footprint pin 7 pad or the R605 junction.

```
MOTOR_EN (from the Connectors zone, J1 pin 3)
    │
   [R_EN1: 10kΩ 1% 0402]
    │
   [R_EN2: 22kΩ 1% 0402] ──── GND
    │
   MOTOR_EN_MON (net label → the Microcontroller zone, PA5)
```

Divider: 22/(10+22) = 0.6875. At 4.4V playback: 3.025V ≤ 3.3V ✓
At auto-off (low): ≈0.2V, below VIL ✓

Schematic note: `MOTOR_EN tap point: IC601 footprint pin 7 pad on WM-D6C main
board. Verify voltage on bench before connecting. See signal-chain-analysis.md §3.`

---

### ADC Inputs — RV601, RV602, RV603 (J1 Pins 4, 5, 6 → PA1, PA2, PA3)

Each potentiometer wiper may be referenced to B+1 and could exceed 3.3V.
The 100Ω series resistor plus BAT54 clamp is the minimum safe configuration.

**⚠ Measure wiper voltage on bench before first power-on.** If any wiper exceeds
3.3V at B+1 = 6V, add a resistor divider before the clamp.

```
RV601 (from the Connectors zone, J1 pin 4)
    │
   [R_ADC1: 100Ω 5% 0402]              ← source impedance limit + protection
    │
   ├──[BAT54, anode→node, cathode→+3V3]  ← overvoltage clamp
   ├──[BAT54, anode→GND, cathode→node]   ← undervoltage clamp
    │
   RV601_WIPER (net label → the Microcontroller zone, PA1/ADC_IN1)
```

Repeat identically for RV602 → PA2 and RV603 → PA3.

Schematic note: `⚠ VERIFY WIPER VOLTAGE BEFORE POWER-ON. See signal-chain-
analysis.md §4 for divider formula. If wiper exceeds 3.3V, add R/2R divider
before the 100Ω series resistor. Adjust ADC scaling in firmware to match.`

---

### Battery Sense (VBAT → ADC) — battery build

```
VBAT ──[R_VS1: 22kΩ 1% 0402]──┬── VBAT_SENSE (net label → the Microcontroller zone, PB0/ADC_IN8)
                              │
                          [R_VS2: 100kΩ 1% 0402]
                              │
                          Q_VS drain  (2N7002 N-FET; gate ← VBAT_SENSE_EN; source → GND)
                              │
   [C_VS: 10nF C0G 0402] ──── GND     (at the VBAT_SENSE node)
```

- Divider ratio 100/122 = 0.82 → 3.7V float presents ~3.03V to the ADC (under 3.3V
  VDDA, with margin); 2.5V floor → ~2.05V.
- Q_VS gates the divider's ground leg so it draws ~0 except during a measurement
  (firmware raises `VBAT_SENSE_EN`, settles, samples, lowers) — no standby pack drain.
- Schematic note: `Source impedance ~18kΩ — allow adequate ADC sample time. See §7.7.`

**Battery level indicator drive:** the five `BATT_LED1…5` lines route from the
Microcontroller zone to J3 (Connectors zone) and on to the WM-D6C LED board. Optional
small series resistors per line may go here; the existing 180Ω limiters (R814–818) live
on the LED board.

### Net labels used in this zone

**Inputs (from other sheets):**
- `MOTOR_PWM` ← the Microcontroller zone (PA6)
- `FG_RAW`, `MOTOR_EN`, `RV601`, `RV602`, `RV603` ← the Connectors zone

**Outputs (to other sheets):**
- `FG_IN` → the Microcontroller zone (PA0)
- `RV601_WIPER`, `RV602_WIPER`, `RV603_WIPER` → the Microcontroller zone
- `MOTOR_EN_MON` → the Microcontroller zone
- `Q601_BASE` → the Connectors zone (J1 pin 2)

**Battery build:**
- `VBAT_SENSE_EN` ← the Microcontroller zone; `VBAT_SENSE` → the Microcontroller zone

---

## Connectors Zone

**Purpose:** Physical boundaries of the board. All connectors and headers.
No signal conditioning — just mechanical connections and net labels.

### J1 — 8-pin JST SH 1.25mm (WM-D6C Interface Harness)

Symbol: `Connector_JST:JST_SH_SM08B-SRSS-TB_1x08-1MP_P1.00mm_Horizontal`
or equivalent 8-pin 1.25mm JST SH footprint.

| J1 Pin | Net Label | Signal | Direction |
|---|---|---|---|
| 1 | `FG_RAW` | FG901 optical sensor output | Machine → Module |
| 2 | `Q601_BASE` | Motor drive to Q601 base | Module → Machine |
| 3 | `MOTOR_EN` | MOTOR_EN net (IC601 pin 7 pad) | Machine → Module |
| 4 | `RV601` | RV601 wiper (base speed trim) | Machine → Module |
| 5 | `RV602` | RV602 wiper (Speed Tune slider) | Machine → Module |
| 6 | `RV603` | RV603 wiper (Speed Tune range) | Machine → Module |
| 7 | `B+1` power symbol | 6V supply rail | Shared |
| 8 | GND power symbol | Chassis ground | Shared |

Pin 7 and Pin 8 use power symbols, not net labels.

**Series diode on J1 pin 7 (B+1 supply line):**

```
B+1 power symbol ──[D_B1: 1N5819, anode]──[cathode]── J1 pin 7
```

Schematic note: `D_B1 prevents reverse current from Sony B+1 rail into DSR-1
converter when Sony is powered and DSR-1 is not. Forward drop ~0.3V at load
current. Machine sees ~5.7V on B+1 — within specification.`

**S601 Speed Tune switch — direct connection, no level shift:**

S601 is rewired to operate at 3.3V logic level. Connect one terminal to `+3V3`
and the other to `SPEED_TUNE_SW`. STM32 PA7 is configured with internal pull-down.
No external components needed.

```
+3V3 ──[S601 switch]── SPEED_TUNE_SW (→ the Microcontroller zone, PA7)
                        │
                       [PA7 internal pull-down ~40kΩ to GND]
```

This pin does not route through J1 — S601 is rewired during installation to
connect directly to the DSR-1 board.

---

### J2 — SWD Debug Header (4-pin 2.54mm, 1×4)

Symbol: `Connector:Conn_01x04_Pin`

| J2 Pin | Net Label | Signal |
|---|---|---|
| 1 | GND | Ground |
| 2 | `SWDCLK` | SWD clock |
| 3 | `SWDIO` | SWD data |
| 4 | `+3V3` | 3.3V reference only |

Schematic note: `J2: SWD programming header. Use STM32CubeProgrammer or OpenOCD.
3.3V pin is reference only — do not use to power the board. Do not bury this
header under the installed board; keep accessible during Rev A development.`

---

### J3 — LED-Board Harness (battery indicator), 7-pin

| J3 Pin | Net | Signal | Direction |
|---|---|---|---|
| 1 | `BATT_LED1` | LED D801 drive | Module → Machine |
| 2 | `BATT_LED2` | LED D802 drive | Module → Machine |
| 3 | `BATT_LED3` | LED D803 drive | Module → Machine |
| 4 | `BATT_LED4` | LED D804 drive | Module → Machine |
| 5 | `BATT_LED5` | LED D805 drive | Module → Machine |
| 6 | `S801_BATT` | S801 BATT-position sense | Machine → Module |
| 7 | GND | Common / return | Shared |

> Schematic note: `⚠ Bench-confirm before wiring J3 (power-supply-design.md §7.7):
> (1) how S801's BATT position reroutes D801–D805 and whether the CX10043 outputs go
> high-impedance there (so the STM32 drives them without contention); (2) LED common
> polarity through the on-board 180Ω limiters, to set drive direction. The stock
> single-LED brightness path (Q801) is left disconnected once the STM32 owns the bar.`

### Test Pads

Add `Device:TestPoint` for each of:

| Reference | Net | Purpose |
|---|---|---|
| TP1 | `+3V3` | MCU supply check |
| TP2 | `B+3` | Motor supply check |
| TP3 | `FG_RAW` | FG oscilloscope probe point |
| TP4 | `Q601_BASE` | Motor drive output check |
| TP5 | `DEBUG_TX` | UART debug / PA9 |
| TP6 | GND | Scope ground reference |

---

## Annotation Scheme

The design is one flat sheet, so annotate in a single pass: Tools → Annotate Schematic
→ Annotate. A single sequential pass is fine; for readability you can group designators
by zone by assigning ranges as you place parts. After merging or adding the battery
block, re-run Annotate to resolve any duplicate designators (e.g. the MCP1700 LDO
should be a single Ux, and the flatten/merge can leave gaps — that is harmless).

## Symbol Properties Checklist

Before running ERC, verify every symbol has:

| Field | Example |
|---|---|
| **Value** | `169kΩ`, `STM32G0C1KCU6`, `MMBT3904` |
| **Footprint** | `DSR-1:STM32G0C1KCU6_UFQFPN32` |
| **Datasheet** | relative path in `hardware/datasheets/` or URL |
| **LCSC** | JLCPCB part number (custom field) |
| **DNP** | `Variant A only`, `Variant B only`, or blank for shared |

---

## ERC — Expected Errors and Resolutions

Run Inspect → Electrical Rules Checker after completing all sheets.

| Error | Cause | Resolution |
|---|---|---|
| Power pin not driven | Missing PWR_FLAG | Add PWR_FLAG on B+1, B+3, +3V3 at the rail source |
| Pin unconnected | Unused STM32 GPIO | Add No-Connect flag (`Q`) |
| Net has no driver | Net-label typo or missing PWR_FLAG | Check label spelling; add PWR_FLAG at the rail source |
| Conflicting net | Duplicate label names | Ensure all labels are unique or intentionally shared |

Target: **zero errors** before moving to PCB layout. Warnings on properly-flagged
DNP open pins are acceptable.

---

## First Commit After Schematic Completion

```
git add hardware/kicad/
git commit -m "DSR-1 Rev A schematic — single D-size sheet, ERC clean, pre-layout

- Single flat D-size sheet (no hierarchy)
- Power zone: USB-C / barrel input, CN3058E charge + LiFePO4 power-path (battery
  build), TPS63070 B+1 buck-boost, MT3608 B+3, MCP1700 3.3V
- MCU zone: STM32G0C1KCU6 decoupling, pin assignments; motor PWM on PA6 (TIM3_CH1)
- Signal zone: FG divider/clamp, NPN motor drive, ADC clamps, VBAT sense
- Connectors zone: J1 harness, J2 SWD, J3 LED board, S601 rewire, test pads
- Rev A targets Ver. 1.0 CX20084 boards (1984-2001)
- ERC: 0 errors"

git tag -a hw-v0.1-schematic-complete -m "Schematic complete, ERC clean, ready for layout review"
git push origin main --tags
```

---

## Distribution & Printing

A single D-size sheet does **not** require downstream users to own a large-format
plotter. For public release (CERN-OHL-P), ship readable artifacts alongside the KiCad
source:

- **Full-size schematic PDF** — `kicad-cli sch export pdf` renders the D-sheet to a PDF
  anyone can open and zoom/pan on screen, or tile-print across letter/A4 in their PDF
  reader's poster/tile mode. Screen review needs no paper at all.
- **(Optional) tiled letter/A4 PDF** — for bench/service use, provide a paginated PDF so
  a single page can sit next to the machine. Generate it in a release script rather than
  maintaining a second schematic by hand.
- **Release file set** — schematic PDF (readable by everyone) + `.kicad_sch`/project (for
  editors) + BOM + gerbers. The source's sheet size never reaches a plotter unless someone
  chooses to send it there.

Example export (from the project directory):

```
kicad-cli sch export pdf hardware/kicad/DSR-1/DSR-1.kicad_sch -o dist/DSR-1-schematic.pdf
```

---

## PCB Layout Priority Constraints

After ERC passes, update the PCB (Tools → Update PCB from Schematic) and begin
placement in this priority order:

1. STM32 decoupling caps within 0.5mm of VDD/VDDA/VDDIO2 pins
2. MT3608 switching loop (VIN cap → L1 → SW → D_BOOST → VOUT cap) as compact as possible; SW node trace ≤3mm
3. USB differential pair: matched length, 90Ω differential impedance, ≤25mm, routed away from MT3608 SW node
4. B+3 motor drive traces: minimum 0.5mm width for 500mA
5. GND pour on both layers; via array under STM32 exposed VSS pad (2×2 or 3×3 grid, 0.3mm drill)
6. Analog signal zone (FG, ADC, motor drive) on opposite side of board from MT3608

See `signal-chain-analysis.md §10` for full layout rule derivations.

---

*Document version: 0.6 — Matches DSR-1 hardware Rev A*
*Replaces: initial draft (v0.1) — corrected motor drive topology, full production run scope added, sheet filenames aligned with actual KiCad project*
*v0.3 adds: battery-integrated charge-in-place (CN3058E + power-path), TPS63070 buck-boost B+1 regulator, and STM32-driven battery level indicator (CX10043 re-reference). Per power-supply-design.md §5.2, §7.*
*v0.4: consolidated power onto a single Power sheet (was Power Input Zone + Power Management); sheets renumbered to 5 total (MCU→3, Signal→4, Connectors→5).*
*v0.6: merged the battery appendix inline — battery/charge/power-path/TPS63070 now live in the Power zone, and the indicator pins/sense/J3 in the MCU, Signal, and Connectors zones; single cohesive guide, no addendum.*
*v0.5: flattened to a single D-size sheet — hierarchy, root sheet, and sheet pins removed; zones replace sheets; added Distribution & Printing.*

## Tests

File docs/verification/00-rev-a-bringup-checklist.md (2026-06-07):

# Rev A Bring-Up Checklist

**Project:** DSR-1 / wmd6c-servo  
**File:** `docs/verification/00-rev-a-bringup-checklist.md`  
**Status:** Draft / pre-Rev A  
**Scope:** Safe bring-up sequence for DSR-1 Rev A hardware before, during, and after installation in a Sony WM-D6C / TC-D6C.

---

## 1. Purpose

This document defines the staged bring-up process for the first DSR-1 hardware revision.

The goal is to validate DSR-1 without damaging the Sony WM-D6C, the DSR-1 board, the USB host, the test equipment, or the motor/transport system.

DSR-1 combines three risk domains:

1. **Servo control** — can run the capstan motor incorrectly if unstable or miswired.
2. **Power conversion / protection** — can damage the Walkman or DSR-1 if polarity, rails, or fault paths are wrong.
3. **USB-C data / PD / service access** — can introduce VBUS, host ground, ESD, power-role, firmware-update, and backfeed risks.

Bring-up must therefore proceed in layers. No later stage may begin until the previous stage has passed or the failure has been documented and corrected.

---

## 2. Safety Position

DSR-1 Rev A must be assumed unsafe until proven otherwise.

Do not connect Rev A to a valuable WM-D6C until:

- bare board inspection passes,
- power rails are verified,
- USB behavior is verified,
- firmware boots and reports sane state,
- all outputs are confirmed safe at reset,
- ADC inputs are verified with simulated voltages,
- FG input is validated with a signal generator,
- motor-control output is validated into dummy loads,
- power-fault behavior is tested,
- and the target WM-D6C has been measured before installation.

The Sony machine should be the **last** thing connected, not the first.

---

## 3. Required Equipment

Minimum recommended equipment:

| Equipment | Purpose |
|---|---|
| Current-limited bench supply | Safe power-up, rail testing, fault testing |
| Digital multimeter | Rail voltage, continuity, resistance checks |
| Oscilloscope | FG waveform, motor-control output, power rail transients |
| Logic analyzer | FG capture, USB/service timing if needed |
| USB power meter / analyzer | USB-C VBUS/current monitoring |
| USB-C breakout / PD analyzer | CC/PD testing if PD is implemented |
| ST-Link or compatible SWD probe | Firmware bring-up and debug |
| USB host computer | CDC/DFU/service validation |
| Signal generator | Simulated FG input |
| Dummy load / resistor load | Motor-output and power-output validation |
| Test tape | Final speed calibration |
| Frequency counter / audio analyzer | Tape speed measurement |
| Wow/flutter meter or equivalent | Final performance validation |
| ESD-safe tools | Handling and installation |
| Magnification / microscope | Solder and PCB inspection |

Optional but useful:

- thermal camera,
- programmable electronic load,
- differential probe,
- bench USB isolator,
- audio analyzer,
- temperature probe,
- variable environmental test setup.

---

## 4. Documentation Required During Bring-Up

Every bring-up session should produce a log.

Recommended path:

```text
docs/measurements/rev-a-bringup-log-YYYY-MM-DD.md
```

Minimum required fields:

| Field | Required |
|---|---:|
| Date | Yes |
| Board revision | Yes |
| PCB serial / assembly ID | Yes |
| Firmware commit / build ID | Yes |
| Test operator | Yes |
| Test equipment | Yes |
| Power source | Yes |
| USB source / host | If used |
| PD controller / configuration | If used |
| Test step | Yes |
| Expected result | Yes |
| Actual result | Yes |
| Pass/fail | Yes |
| Raw measurements | Yes |
| Photos/screenshots | If relevant |
| Corrective action | If failed |

No “works fine” notes. Record numbers.

---

## 5. Stage Gate Summary

| Stage | Name | Sony WM-D6C connected? | Pass required before |
|---:|---|---:|---|
| 0 | Design-file review | No | PCB order / assembly |
| 1 | Bare board inspection | No | Power application |
| 2 | Unpowered electrical checks | No | Rail bring-up |
| 3 | Current-limited first power | No | MCU power-up |
| 4 | 3.3 V / local rail validation | No | SWD / firmware |
| 5 | SWD and firmware flash | No | USB/service |
| 6 | USB-C data validation | No | PD / VBUS testing |
| 7 | USB-C PD / VBUS validation | No | Output enable testing |
| 8 | Safe-state validation | No | ADC/PWM/FG tests |
| 9 | ADC input validation | No | Speed-control connection |
| 10 | PWM output validation | No | Motor-control connection |
| 11 | FG input validation | No | Servo simulation |
| 12 | Servo loop simulation | No | Sony preinstall work |
| 13 | Power-fault testing | No | Sony connection |
| 14 | WM-D6C preinstall measurements | Yes, unmodified | DSR-1 install |
| 15 | Passive Sony connection checks | Yes | Powered Sony tests |
| 16 | Powered Sony no-motor tests | Yes | Motor-control enable |
| 17 | Motor staged enable | Yes | Transport test |
| 18 | Real transport servo test | Yes | Speed calibration |
| 19 | Speed calibration | Yes | Wow/flutter testing |
| 20 | USB service during playback | Yes | Soak testing |
| 21 | Long-run soak test | Yes | Release claims |

---

## 6. Stage 0 — Design-File Review

Before ordering or assembling Rev A hardware:

### 6.1 Schematic Review

Confirm:

- every Sony-facing signal is listed in `wmd6c-interface-contract.md`,
- every power/USB signal is listed in `power-usb-c-architecture.md`,
- every clock assumption is listed in `timebase-decision.md`,
- every target board assumption is listed in `wmd6c-revision-compatibility.md`.

Checklist:

| Item | Status |
|---|---|
| FG input protection present | Pending |
| Motor-control safe-state present | Pending |
| ADC input protection/scaling present | Pending |
| USB D+/D− ESD protection present | Pending |
| USB-C CC strategy present | Pending |
| VBUS protection present | Pending |
| Reverse-polarity protection present if external DC retained | Pending |
| Overcurrent protection present | Pending |
| Backfeed paths reviewed | Pending |
| SWD access present | Pending |
| BOOT0/update access present | Pending |
| Test points present | Pending |
| External/reference timebase decision reflected | Pending |

### 6.2 PCB Review

Confirm:

- USB-C connector has mechanical support,
- USB D+/D− routing is short and intentional,
- shield/ground strategy is implemented deliberately,
- high-current motor/power paths are separated from FG/ADC references,
- analog inputs are not routed beside switching nodes,
- test pads are accessible after assembly,
- no pads require impossible soldering during installation,
- board outline fits intended cavity,
- connector/cable routing is realistic.

### 6.3 BOM Review

Confirm:

- all active parts are available,
- substitutes are documented,
- voltage/current ratings have margin,
- protection devices are correctly rated,
- regulator thermal behavior is plausible,
- USB-C connector is mechanically suitable,
- PD controller selection is documented if external PD is used.

---

## 7. Stage 1 — Bare Board / Assembly Inspection

Before power is applied:

### 7.1 Visual Inspection

Inspect under magnification:

| Area | Check |
|---|---|
| MCU pins | Bridges, opens, orientation |
| USB-C connector | Solder joints, shell tabs, pin bridges |
| PD controller, if present | Orientation and bridges |
| Regulators | Orientation and thermal pad |
| Protection devices | Orientation, correct placement |
| PWM output path | Incorrect values, shorts |
| FG input path | Incorrect values, shorts |
| ADC input network | Incorrect values, shorts |
| SWD/BOOT pads | Accessibility |
| Test pads | Accessibility |

### 7.2 Assembly Record

Record:

- PCB revision,
- assembly date,
- parts substitutions,
- missing/DNP parts,
- known rework,
- photos of top and bottom.

---

## 8. Stage 2 — Unpowered Electrical Checks

Before applying power:

### 8.1 Continuity / Resistance Checks

Measure resistance:

| Measurement | Expected |
|---|---|
| 3.3 V to GND | No short |
| VBUS to GND | No short |
| RAW_POWER to GND | No short |
| MOTOR_CTRL to GND | No short unless designed |
| FG_IN to GND | No unexpected short |
| USB shield to GND | Matches intended strategy |
| SWDIO/SWDCLK to GND | No short |
| BOOT0 to expected pull | Matches design |

### 8.2 Diode-Mode / Protection Checks

Check:

- ESD devices not shorted,
- reverse-polarity path not shorted,
- ideal diode / MOSFET orientation,
- regulator input/output behavior,
- USB VBUS path not shorted to system rails.

Do not continue if any rail is shorted.

---

## 9. Stage 3 — First Power Application

Use current-limited bench supply.

### 9.1 Initial Conditions

- No Sony WM-D6C connected.
- No motor connected.
- USB disconnected unless specifically testing VBUS.
- SWD disconnected unless needed.
- Current limit set low.
- Scope or meter on 3.3 V rail.

### 9.2 Power-Up Checklist

| Step | Action | Pass condition |
|---:|---|---|
| 1 | Apply low input voltage if regulator allows | No overcurrent |
| 2 | Increase to nominal input | No overcurrent |
| 3 | Measure 3.3 V | Within expected tolerance |
| 4 | Measure MCU reset state | Valid |
| 5 | Check regulator temperature | No rapid heating |
| 6 | Check VBUS/backfeed | No unintended voltage |
| 7 | Check motor output node | Safe inactive state |

Record input voltage, current, 3.3 V, temperature, and output states.

---

## 10. Stage 4 — Local Rail Validation

Validate all DSR-1-generated rails.

| Rail | Test | Pass condition |
|---|---|---|
| `+3V3` | No-load and firmware-load voltage | Stable |
| `VBUS_SENSE`, if present | Correct scaling | Safe ADC/GPIO level |
| `RAW_POWER_SENSE`, if present | Correct scaling | Safe ADC/GPIO level |
| Motor/support rail, if generated | Dummy load test | Stable and current-limited |
| PD-negotiated rail, if present | Contract voltage test | Correct and protected |

Add dummy loads before connecting Sony rails.

---

## 11. Stage 5 — MCU Boot, SWD, and Firmware Flash

### 11.1 SWD Validation

Confirm:

- SWD connects reliably,
- chip ID is read correctly,
- erase/program succeeds,
- reset works,
- firmware starts,
- debug halt/resume does not drive motor output unsafe.

### 11.2 Firmware Boot Validation

Firmware should report:

- firmware version,
- board/config ID,
- clock source,
- reset reason,
- rail status,
- USB status,
- servo disabled state,
- calibration/settings status.

Pass condition:

> Firmware boots with servo output disabled until explicitly armed by valid state conditions.

---

## 12. Stage 6 — USB-C Data Validation

No Sony machine connected.

### 12.1 USB Electrical

Check:

| Test | Pass condition |
|---|---|
| USB attach | No overcurrent |
| VBUS | Correct voltage and no unintended backfeed |
| USB enumeration | Device appears consistently |
| USB disconnect | No reset unless expected |
| USB reconnect | Recovers consistently |
| USB shield behavior | Matches intended strategy |

### 12.2 USB CDC / Service

Verify:

- terminal connects,
- banner prints,
- telemetry command works,
- invalid commands are rejected,
- command spam does not lock firmware,
- telemetry rate limiting works,
- USB disconnect during telemetry is safe.

### 12.3 USB Noise Baseline

With oscilloscope:

- observe 3.3 V during USB attach,
- observe motor-output safe-state node,
- observe FG input idle state,
- confirm USB does not create large rail disturbances.

---

## 13. Stage 7 — USB-C PD / VBUS Validation

If PD is implemented in Rev A:

### 13.1 PD Contract Test

Check:

| Test | Pass condition |
|---|---|
| Cable attach | Safe default |
| PD negotiation | Expected voltage/current |
| Cable flip | Same behavior |
| Non-PD charger | Safe behavior |
| Low-current source | Safe behavior |
| Disconnect | No unsafe output |
| Renegotiation | No unsafe output |
| Brownout | Safe reset/fault state |

### 13.2 PD Failure Behavior

Test:

- no contract,
- wrong voltage,
- undervoltage,
- overvoltage,
- rapid detach/attach,
- host/source reset,
- controller fault if external PD controller is used.

Pass condition:

> PD fault state never enables motor output or backfeeds Sony rails.

---

## 14. Stage 8 — Reset and Safe-State Validation

Before testing active inputs/outputs, prove every unsafe output defaults safe.

Test safe state during:

| Condition | Required behavior |
|---|---|
| No firmware | Motor output safe |
| Reset held | Motor output safe |
| Bootloader / DFU | Motor output safe |
| Firmware crash / watchdog | Motor output safe |
| USB attach | Motor output safe |
| PD negotiation | Motor output safe |
| Flash write | Motor output held safe or controlled |
| Brownout | Motor output safe |
| SWD halt | Motor output safe |

Pass condition:

> The motor-control path is not dependent solely on firmware behaving correctly.

---

## 15. Stage 9 — ADC Input Validation

No Sony machine connected.

Use known voltages or a test jig to validate each ADC path.

Signals:

- `RV601_WIPER`
- `RV602_WIPER`
- `RV603_WIPER`
- rail sense inputs, if present
- temperature/reference inputs, if present

Checklist:

| Test | Pass condition |
|---|---|
| 0 V input | ADC near expected low |
| Midscale input | ADC near expected mid |
| Full safe input | ADC near expected high |
| Slight overrange through protection | No damage; clamp behavior as designed |
| Open input | Firmware handles safely |
| Noisy input | Filtering acceptable |

Firmware should report raw ADC values over USB.

---

## 16. Stage 10 — PWM Output Validation

No Sony machine connected.

Use dummy load and oscilloscope.

### 16.1 PWM Output

| Test | Pass condition |
|---|---|
| PWM frequency | Expected |
| Duty range | Expected |
| RC-filter output | Acceptable ripple |
| Level shift | Correct output range |
| Reset state | Safe |
| EMI/noise baseline | Acceptable before Sony install |
| USB command update | No glitch |
| Flash write | Holds safe behavior |

Pass condition:

> Motor-control output is predictable, bounded, and safe before connecting to the Sony circuit.

---

## 17. Stage 11 — FG Input Validation With Signal Generator

No Sony machine connected.

Use signal generator or logic source.

Test:

| Input | Expected result |
|---|---|
| Nominal FG frequency | Correct measured period |
| Half-speed frequency | Correct measured period |
| Double-speed frequency | Correct measured period |
| Too-fast pulses | Rejected or handled |
| Missing pulses | Servo enters safe/unlocked state |
| Noisy signal | Conditioning/firmware handles or failure documented |
| Startup pulse train | Lock behavior acceptable |

Telemetry should report:

- measured period,
- computed frequency,
- target period,
- error,
- servo state,
- rejected pulses if counted.

---

## 18. Stage 12 — Servo Loop Simulation

No Sony machine connected.

Use simulated FG and dummy output.

Test:

- proportional response sign,
- integral behavior,
- anti-windup,
- output clamps,
- lock/unlock state,
- speed target changes,
- RV input influence,
- USB live tuning,
- flash save/restore,
- reset recovery.

Pass condition:

> The servo loop behaves correctly against simulated signals before real motor hardware is connected.

---

## 19. Stage 13 — Power-Fault Tests

No Sony machine connected.

Perform with current-limited supplies.

Required tests:

| Test | Pass condition |
|---|---|
| Reverse polarity | No damage; protected behavior |
| Overvoltage | Protection engages safely |
| Overcurrent | Limit/fuse behaves as designed |
| Shorted load | No unsafe heating or rail damage |
| USB plus external power | No backfeed |
| Battery rail simulation plus USB | No backfeed |
| SWD plus unpowered board | No unintended powering |
| PD failure | Safe state |

Document exact voltages, currents, durations, and protection behavior.

---

## 20. Stage 14 — WM-D6C Preinstall Measurements

Before modifying the Sony unit, perform `01-wmd6c-preinstall-measurements.md`.

Minimum required before connection:

- board photos,
- board revision notes,
- serial number,
- CN301 behavior,
- CP304 behavior,
- battery rail behavior,
- FG waveform,
- motor-control node voltage,
- RV601/RV602/RV603 voltages,
- S601 logic,
- ground reference notes.

No DSR-1 connection should be made until the target unit is documented.

---

## 21. Stage 15 — Passive Sony Connection Checks

With DSR-1 unpowered and Sony unpowered:

- verify harness continuity,
- verify no shorts to ground,
- verify no unexpected loading of Sony nodes,
- verify no backfeed from DSR-1 to Sony rails,
- verify all connection points against photos and notes.

With DSR-1 powered but Sony motor disabled:

- verify Sony nodes are not pulled to unsafe voltages,
- verify USB connection does not energize Sony motor rail unless designed,
- verify outputs remain safe.

---

## 22. Stage 16 — Powered Sony, Motor Disabled

Connect DSR-1 to Sony measurement points, but keep motor-control output disabled.

Check:

| Test | Pass condition |
|---|---|
| Sony power on | DSR-1 remains stable |
| USB service connected | No rail disturbance |
| ADC readings | Match measured Sony wiper voltages |
| FG input idle/play manually observed | Safe reading |
| Motor output disabled | No unintended motor drive |
| Power rails | Within expected range |

Do not enable motor output until all readings match preinstall measurements.

---

## 23. Stage 17 — Motor-Control Staged Enable

Enable motor-control output in stages.

Suggested progression:

1. Output connected to Sony node but held at safe inactive value.
2. Output moved slightly within measured safe range.
3. Confirm motor response.
4. Confirm direction/sign of correction.
5. Enable limited-range servo.
6. Enable full-range servo only after stable behavior.

Abort immediately if:

- motor runs away,
- output saturates unexpectedly,
- current rises abnormally,
- FG disappears,
- USB/telemetry stalls,
- rail collapses,
- audible mechanical distress occurs.

---

## 24. Stage 18 — Real Transport Servo Test

With tape transport operating:

Record:

- FG period,
- target period,
- output value,
- error,
- integral,
- ADC values,
- rail voltages,
- USB state,
- motor current if measurable,
- audio output frequency if using test tape.

Test:

- Play start,
- Stop,
- Pause if applicable,
- USB connect/disconnect,
- Speed Tune enable/disable,
- RV602 sweep within safe limits,
- warmup behavior.

Pass condition:

> Servo controls capstan speed without runaway, oscillation, audible hunting, rail collapse, or USB-induced disturbance.

---

## 25. Stage 19 — Speed Calibration

Using the Sony service adjustment mindset:

- use regulated power or documented power source,
- use calibrated test tape,
- measure output frequency,
- adjust target/calibration,
- save configuration,
- power cycle,
- verify calibration persists.

Record:

- test tape identity,
- measurement instrument,
- power mode,
- target period,
- FG frequency,
- audio output frequency,
- final saved settings.

---

## 26. Stage 20 — USB Service During Playback

With the machine running stably:

Test:

| Action | Required result |
|---|---|
| Connect USB | No speed disturbance |
| Start telemetry | No speed disturbance |
| Stop telemetry | No speed disturbance |
| Send invalid command | Rejected safely |
| Adjust tuning slightly | Expected controlled response |
| Save settings | No audible/servo instability |
| Disconnect USB | No speed disturbance |
| Host suspend/resume | Safe behavior |

If USB-C PD powers the transport, also test PD-specific behavior during playback.

---

## 27. Stage 21 — Long-Run Soak Test

Run at least one extended test after initial validation.

Record:

- duration,
- power mode,
- USB state,
- ambient temperature,
- rail voltage at start/end,
- FG period drift,
- output drift,
- speed drift,
- temperature rise,
- motor behavior,
- any faults.

Suggested minimum:

| Test | Minimum duration |
|---|---:|
| Servo only bench simulation | 30 minutes |
| Transport play test | One full tape side |
| USB telemetry during play | 30 minutes |
| Power/thermal soak | 1 hour minimum |

---

## 28. Release Claim Gate

Do not claim any of the following until supported by logs:

| Claim | Required evidence |
|---|---|
| Drop-in replacement | Successful install documentation |
| Safe power input | Fault testing |
| USB-C service ready | Enumeration, telemetry, update tests |
| USB-C PD ready | PD tests across chargers/cables |
| Better than original speed | Speed and wow/flutter measurements |
| Compatible with WM-D6C | Board revision and validation evidence |
| Compatible with all WM-D6C revisions | Multiple revision validations |

---

## 29. Final Rule

The Rev A board is not proven when it powers up.

It is proven only when it can be measured, faulted, reset, connected, disconnected, tuned, updated, and run in a real WM-D6C without creating a new failure mode.

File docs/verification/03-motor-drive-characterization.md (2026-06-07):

# Motor-Drive Characterization

**Project:** DSR-1 / wmd6c-servo  
**File:** `docs/verification/03-motor-drive-characterization.md`  
**Status:** Draft / pre-Rev A
**Scope:** Procedure for measuring the Sony WM-D6C motor-control network to confirm DSR-1 output stage sizing and characterize servo tuning parameters.

---

## 1. Purpose

This document defines the required procedure for characterizing the WM-D6C capstan motor-drive interface before connecting DSR-1 to the Sony motor-control network.

The DSR-1 servo loop can only control tape speed safely if its output stage matches the electrical behavior expected by the original Sony circuit.

For **Ver. 1.0 CX20084 boards**, the output stage is already committed:
PWM + RC filter + NPN level-shift (TIM3_CH1 PA6 → Q_LS MMBT3904 → Q601 base).
Q601 exact part/package and base operating range on the C11-494-12 SMD board remain
pending physical confirmation. Direct DAC drive is not used.

This procedure now answers:

- What is Q601's actual base voltage range during playback? (Needed for R9 sizing)
- What is the motor-control node impedance?
- What happens during Stop, Play startup, steady Play, and Speed Tune movement?
- How much current does the motor path require? (Needed for power protection sizing)
- What is the servo loop sign? (Confirm firmware PI convention)
- What clamp values are appropriate for the firmware output limits (`DAC_MIN` and
  `DAC_MAX`, retained names for PWM compatibility)?

---

## 2. Safety Position

The motor-control output is one of the highest-risk DSR-1 interfaces.

An incorrect output stage can:

- run the capstan motor at full speed,
- stall the motor,
- overheat the motor drive path,
- damage Q601 or surrounding circuitry,
- damage the STM32,
- corrupt speed calibration,
- or mechanically stress the tape transport.

Do not connect DSR-1 output to the Sony motor-control node until the original node has been measured and a dummy-load output test has passed.

---

## 3. Prerequisites

Complete or review these first:

```text
docs/hardware/wmd6c-interface-contract.md
docs/hardware/power-usb-c-architecture.md
docs/verification/00-rev-a-bringup-checklist.md
docs/verification/01-wmd6c-preinstall-measurements.md
docs/verification/02-fg901-waveform-capture.md
```

Before beginning:

- identify unit serial number,
- photograph the motor-drive area,
- identify Q601 and associated drive components,
- select a ground point,
- define safe power source,
- and confirm the machine can be powered safely.

---

## 4. Required Equipment

| Equipment | Purpose |
|---|---|
| Oscilloscope | Motor-control node and rail waveform |
| DMM | DC voltage/current checks |
| Current-limited bench supply | Safe external power |
| Current probe or series measurement setup | Motor current estimate |
| Test tape | Real transport load |
| Audio frequency counter / analyzer | Speed reference |
| Thermal camera or temperature probe | Detect overheating |
| Camera | Probe-point documentation |
| Optional differential probe | Safer motor/drive measurements |
| Optional electronic load | DSR-1 output-stage bench simulation |

---

## 5. Measurement Log

Recommended path:

```text
docs/measurements/wm-d6c-serial-72795-motor-drive-YYYY-MM-DD.md
```

Minimum metadata:

| Field | Required |
|---|---:|
| Date | Yes |
| Operator | Yes |
| Unit serial number | Yes |
| Board revision | If known |
| Probe point | Yes |
| Ground point | Yes |
| Power source | Yes |
| Tape state | Yes |
| Speed Tune state | If relevant |
| Instrument settings | Yes |
| Raw values | Yes |
| Screenshots | Yes |
| Interpretation | Yes |

---

## 6. Node Identification

Identify the motor-control node before measuring.

Potential reference area:

| Sony reference | Purpose |
|---|---|
| Q601 | Primary motor-control transistor area |
| Q603–Q605 | Supporting motor-control path, pending schematic confirmation |
| M901 | Capstan motor |
| IC601 / CX20084 area | Original servo output context |

Document:

- exact probe point,
- exact ground point,
- surrounding components,
- whether node is before/after a resistor/transistor,
- whether node connects directly to a transistor base/gate,
- whether node remains connected to IC601 during measurement,
- and whether any prior repair is present.

Take annotated photos.

---

## 7. Required Measurements

### 7.1 Stop / Inactive State

Measure the motor-control node while the transport is stopped.

| Measurement | Value |
|---|---:|
| Control node DC voltage | Pending |
| Motor terminal voltage | Pending |
| Motor current | Pending |
| Rail voltage | Pending |
| Noise/ripple | Pending |
| Node impedance estimate | Pending |

Questions:

- What is the safe inactive state?
- Does the node float?
- Is it pulled up or down?
- Does the original circuit actively brake or simply remove drive?
- What state should DSR-1 present during reset?

### 7.2 Play Startup

Capture startup transient.

| Measurement | Value |
|---|---:|
| Control node initial voltage | Pending |
| Control node peak voltage | Pending |
| Control node settling voltage | Pending |
| Startup duration | Pending |
| Motor current peak | Pending |
| Rail sag | Pending |
| FG begins after | Pending |

Questions:

- Does startup demand a large correction?
- Does the node exceed the STM32's safe direct-drive range?
- Is a soft-start needed?
- Does the motor current surge affect DSR-1 power design?
- Does DSR-1 need to delay servo lock until FG is stable?

### 7.3 Steady Play

Measure steady-state behavior.

| Measurement | Value |
|---|---:|
| Control node DC voltage | Pending |
| Control node ripple/noise | Pending |
| Motor terminal voltage | Pending |
| Motor current | Pending |
| Rail voltage | Pending |
| FG frequency | Pending |
| Audio test tone frequency | If available |

Questions:

- What is the normal operating voltage?
- How much headroom exists above and below normal?
- Is the control signal quiet or noisy?
- Is the loop likely voltage-driven or current-driven?
- Is output filtering needed?

### 7.4 Speed Correction Behavior

If safe, observe motor-control node while speed is adjusted.

Conditions:

| Condition | Control voltage | FG frequency | Audio frequency | Notes |
|---|---:|---:|---:|---|
| Normal speed | Pending | Pending | Pending | |
| Speed Tune min | Pending | Pending | Pending | |
| Speed Tune max | Pending | Pending | Pending | |
| Slight mechanical load, if safe | Pending | Pending | Pending | |

Questions:

- Which direction increases motor speed?
- What voltage change corresponds to speed change?
- How sensitive is the control node?
- Does the original loop saturate?

### 7.5 Power Mode Comparison

Measure under:

| Power mode | Required? | Notes |
|---|---:|---|
| Battery | Yes, if safe |
| Regulated external DC | Yes |
| USB-C power | Later, after DSR-1 exists |
| Low-voltage condition | Optional / caution |

Questions:

- Does motor-control voltage depend strongly on supply mode?
- Does rail sag change control behavior?
- Does DSR-1 need rail compensation?

---

## 8. Current Measurement

Motor current matters for power protection and PD sizing.

Recommended measurements:

| Measurement | Value |
|---|---:|
| Stop current | Pending |
| Startup peak current | Pending |
| Steady Play current | Pending |
| Current during load disturbance | Pending |
| Current during Speed Tune change | Pending |
| Current during low-voltage operation | Pending |

Notes:

- Use current-limited supply.
- Avoid inserting too much series resistance.
- Document measurement method.
- Capture startup with scope if possible.

---

## 9. Output Stage — Confirmed Design

The motor output stage for Ver. 1.0 CX20084 boards is committed:

**TIM3_CH1 PWM (PA6) → R7/C8 RC filter → Q_LS (MMBT3904 NPN) → R9 pullup to B+1 → Q601 base**

This measurement procedure does not choose the output stage — that decision is made.
The measurements in this procedure are used to:

1. **Confirm R9 sizing.** R9 (100kΩ pullup to B+1, currently planned) sets the
   Q601 base voltage when Q_LS is off. Verify the measured inactive-state base
   voltage matches the expected safe-off condition (base at or near B+1, Q601
   firmly off). Adjust R9 if needed.

2. **Confirm output clamps.** The `DAC_MIN` and `DAC_MAX` names in `config.h` are
   retained for firmware compatibility, but they limit PWM duty. The clamp values must keep
   the motor within safe operating range. Measure the base voltage corresponding
   to maximum safe drive and minimum safe drive, then back-calculate the required
   PWM clamp values.

3. **Confirm PI sign convention.** Verify that increasing PWM duty cycle increases
   motor speed (expected: higher duty → Q_LS conducts more → Q601 base pulled
   lower → more collector current → faster motor).

---

## 10. Safe-State Requirements

The selected output stage must be safe during:

| Condition | Required behavior |
|---|---|
| DSR-1 unpowered | No backfeed / no motor drive |
| MCU reset | Motor-control node safe |
| BOOT0 / DFU | Motor-control node safe |
| Firmware crash | Motor-control node safe |
| SWD halt | Motor-control node safe |
| USB attach | No output glitch |
| PD negotiation | No output glitch |
| Brownout | Motor-control node safe |
| Flash write | Output held safe or controlled |

A passive default state is preferred over firmware-only safety.

---

## 11. Dummy-Load Validation Before Sony Connection

Before connecting to Sony:

1. Build or simulate equivalent load based on measured motor-control node.
2. Drive output through full expected range.
3. Confirm voltage/current limits.
4. Confirm reset state.
5. Confirm output with USB connected/disconnected.
6. Confirm output during firmware update mode.
7. Confirm output during power faults.

Do not connect to the Sony motor-control node until dummy-load behavior is documented.

---

## 12. Firmware Consequences

The measurements determine firmware requirements.

| Measured behavior | Firmware implication |
|---|---|
| Output sign positive | Confirm PI sign |
| Output sign negative | Invert correction direction |
| Narrow control range | Tight output clamps |
| Sensitive node | Lower gains / filtering |
| Startup transient large | Add acquisition/soft-start |
| Rail-dependent behavior | Add rail sensing or compensation |
| No FG at startup | Hold output until valid FG |
| Motor runaway risk | Add watchdog/fault state |

Firmware telemetry should report:

- output command,
- output clamp state,
- measured FG period,
- target period,
- error,
- integral,
- lock state,
- rail status,
- USB state,
- and fault state.

---

## 13. Acceptance Criteria

Motor-drive characterization is accepted when:

| Requirement | Status |
|---|---|
| Probe point photographed | Pending |
| Ground point photographed | Pending |
| Stop/inactive voltage measured | Pending |
| Startup transient captured | Pending |
| Steady Play voltage measured | Pending |
| Motor current estimated/measured | Pending |
| Rail sag measured | Pending |
| Speed correction direction identified | Pending |
| Output voltage range defined | Pending |
| Safe inactive state defined | Pending |
| R9 sizing confirmed from measured base voltage | Pending |
| PWM output clamp values (`DAC_MIN` / `DAC_MAX` names) derived | Pending |
| PI sign convention confirmed | Pending |
| Dummy-load output test plan written | Pending |
| Firmware implications documented | Pending |

---

## 14. Output of This Procedure

This procedure should produce:

1. Measurement log.
2. Probe-point photos.
3. Oscilloscope captures.
4. Motor-control voltage table.
5. Motor-current estimates.
6. Output-stage recommendation.
7. Safe-state requirements.
8. Firmware control-sign and clamp requirements.
9. Open questions for Rev A schematic.

---

## 15. Final Rule

Do not let DSR-1 drive the WM-D6C motor-control node until the original node has been measured and the DSR-1 output stage has passed dummy-load testing.

The motor should be the last thing trusted, not the first.

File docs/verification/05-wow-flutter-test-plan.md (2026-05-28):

# Wow and Flutter Test Plan

**Project:** DSR-1 / wmd6c-servo  
**File:** `docs/verification/05-wow-flutter-test-plan.md`  
**Status:** Draft / pre-Rev A  
**Scope:** Procedure for measuring speed stability, wow/flutter behavior, drift, and USB/power-related disturbance after DSR-1 installation.

---

## 1. Purpose

This document defines the wow/flutter and speed-stability test plan for DSR-1.

DSR-1 must not be considered successful merely because the motor runs or the servo reports lock. The Sony WM-D6C is a precision cassette transport. DSR-1 must demonstrate that it can control the capstan without introducing unacceptable speed error, hunting, drift, oscillation, power-related instability, or USB-induced disturbance.

This plan answers:

- Does DSR-1 maintain correct tape speed?
- Does it introduce measurable wow or flutter?
- Does speed drift over time?
- Does USB telemetry affect speed?
- Does USB-C power or PD negotiation affect speed?
- Does power source affect servo behavior?
- Does Speed Tune behave safely and predictably?
- Is performance good enough to justify claims in the README?

---

## 2. Test Philosophy

The test must measure the actual transport, not just firmware telemetry.

DSR-1 telemetry is useful, but it is not the final proof. The final proof is measured playback behavior from a known tape reference.

A valid test should document:

1. the machine,
2. the DSR-1 hardware revision,
3. the firmware build,
4. the timebase configuration,
5. the power source,
6. the USB state,
7. the test tape or measurement source,
8. the measurement instrument,
9. raw readings,
10. and the interpretation.

Do not claim “better than original,” “quartz-lock equivalent,” or “WM-D6C compatible” without measured evidence.

---

## 3. Prerequisites

Before running this plan, complete or review:

```text
docs/verification/00-rev-a-bringup-checklist.md
docs/verification/01-wmd6c-preinstall-measurements.md
docs/verification/02-fg901-waveform-capture.md
docs/verification/03-motor-drive-characterization.md
docs/verification/04-speed-calibration-procedure.md
docs/hardware/timebase-decision.md
docs/hardware/power-usb-c-architecture.md
```

Required before wow/flutter testing:

| Requirement | Status |
|---|---|
| DSR-1 installed without unsafe behavior | Required |
| Servo locks during playback | Required |
| Speed calibration completed | Required |
| Firmware settings saved and restored | Required |
| USB telemetry functional | Required |
| Power rails stable | Required |
| Motor output not saturating during normal play | Required |
| No mechanical distress from transport | Required |

A mechanically unhealthy tape transport invalidates the test. DSR-1 cannot compensate for all mechanical defects.

---

## 4. Required Equipment

| Equipment | Purpose |
|---|---|
| Calibrated test tape | Tape-speed reference |
| Wow/flutter meter | Primary wow/flutter measurement |
| Audio analyzer | Alternate speed/wow/flutter measurement |
| Frequency counter | Playback tone frequency |
| Oscilloscope | FG and output correlation |
| USB host/logger | DSR-1 telemetry logging |
| Regulated DC supply | Controlled external power |
| Batteries or battery simulator | Battery-mode testing |
| USB-C power meter/analyzer | USB-C power testing |
| PD analyzer, if applicable | PD contract/renegotiation testing |
| Temperature probe | Drift and warmup testing |
| Measurement log | Raw data capture |

If a dedicated wow/flutter meter is unavailable, use the best available audio analyzer method and clearly mark the result as provisional.

---

## 5. Measurement Log

Recommended path:

```text
docs/measurements/wm-d6c-serial-72795-wow-flutter-YYYY-MM-DD.md
```

Minimum metadata:

| Field | Required |
|---|---:|
| Date | Yes |
| Operator | Yes |
| Unit serial number | Yes |
| DSR-1 hardware revision | Yes |
| Firmware commit/build | Yes |
| Timebase configuration | Yes |
| Power mode | Yes |
| USB state | Yes |
| Test tape identity | Yes |
| Measurement instrument | Yes |
| Measurement standard / weighting | If available |
| Ambient temperature | Yes |
| Warmup time | Yes |
| Raw readings | Yes |
| Interpretation | Yes |

---

## 6. Terms

Use terms carefully.

| Term | Meaning |
|---|---|
| Speed error | Difference between measured playback frequency and expected frequency |
| Drift | Slow change in speed over time |
| Wow | Low-frequency speed variation |
| Flutter | Higher-frequency speed variation |
| WRMS | Weighted root-mean-square measurement, if instrument supports it |
| Peak | Peak deviation measurement, if instrument supports it |
| Servo lock | Firmware state indicating FG loop is stable |
| Output saturation | Servo output at clamp limit, meaning control authority is exhausted |

If the instrument reports multiple standards or weightings, record all relevant settings.

---

## 7. Test Conditions

### 7.1 Required Operating Conditions

| Condition | Required? | Notes |
|---|---:|---|
| Regulated external DC | Yes | Service reference condition |
| Battery operation | Yes, if supported |
| USB connected, data only | Yes |
| USB disconnected | Yes |
| USB telemetry active | Yes |
| USB telemetry idle | Yes |
| USB-C power / PD | Yes, if implemented |
| Speed Tune off | Yes |
| Speed Tune on / centered | Yes, if supported |
| Warm transport | Yes |
| Cold start | Yes |

### 7.2 Optional Conditions

| Condition | Purpose |
|---|---|
| Low battery simulation | Check dropout behavior |
| Multiple tapes | Verify test repeatability |
| Different USB hosts | Detect host/ground differences |
| Different USB-C chargers | Detect PD/power differences |
| Case open vs closed | Thermal/mechanical comparison |

---

## 8. Baseline Before DSR-1 Claims

If possible, record original-unit performance before modification.

| Measurement | Original unit value | Notes |
|---|---:|---|
| Playback frequency | Pending | |
| Speed error | Pending | |
| Wow/flutter WRMS | Pending | |
| Wow/flutter peak | Pending | |
| Power mode | Pending | |
| Speed Tune state | Pending | |
| Warmup time | Pending | |

If original performance cannot be measured because the unit is failed, mark this clearly.

Do not invent baseline performance.

---

## 9. DSR-1 Measurement Sequence

### 9.1 Cold Start Speed

Procedure:

1. Let unit rest unpowered long enough to be considered cold.
2. Insert test tape.
3. Apply selected power mode.
4. Start playback.
5. Begin audio frequency measurement immediately.
6. Begin DSR-1 telemetry logging.
7. Record readings at defined time intervals.

Table:

| Time | Audio frequency | Speed error | FG period | Servo output | Temperature | Notes |
|---:|---:|---:|---:|---:|---:|---|
| 0 min | Pending | Pending | Pending | Pending | Pending | |
| 1 min | Pending | Pending | Pending | Pending | Pending | |
| 5 min | Pending | Pending | Pending | Pending | Pending | |
| 10 min | Pending | Pending | Pending | Pending | Pending | |
| 20 min | Pending | Pending | Pending | Pending | Pending | |
| 30 min | Pending | Pending | Pending | Pending | Pending | |
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

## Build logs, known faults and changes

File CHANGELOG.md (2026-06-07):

# Changelog

All notable changes to the wmd6c-servo project are documented here.

This file is written in plain English, not git log summaries. Each entry describes
what changed, why it changed, and whether existing boards or installations are
affected. The format is designed to be readable by someone who owns an installed
module and wants to know whether they need to update.

---

## [Unreleased] — Design Phase

### Hardware
- Board outline pending: CP304 cavity dimensions to be measured on SN72795 unit
  arriving 2 June 2025
- Motor output stage committed to PWM + RC filter + NPN level-shift (TIM3_CH1 PA6):
  direct DAC drive is rejected for the primary C11-494-12 SMD CX20084 board. Q601
  exact package/marking and base voltage measurement still required to confirm R9
  sizing and PWM-to-speed sign.
- R3/R4 FG divider values pending: FG901 swing voltage measurement required on
  target unit

### Firmware
- All peripheral initialisation code pending bench verification of hardware
- FG_TARGET_HZ pending test tape measurement on target unit
- Initial PI constants (Kp = 0.15, Ki = 0.008) are simulation-derived starting
  points — will be updated with bench-tuned values after first hardware build

### Documentation
- Installation guide pending: requires photographs of actual installation on SN72795
- Bench measurement log for SN72795 pending machine arrival
- Theory documents complete: original servo circuit, digital PLL servo, fixed-point
  arithmetic, why this failed

---

## How to Read This File

Each entry is tagged with one of:

**Hardware** — changes to the KiCad schematic, PCB layout, gerbers, or BOM. If your
board is already manufactured, check whether the change affects your revision.

**Firmware** — changes to the C source code or config constants. Pre-built binaries
for each release are in `firmware/releases/`. Update via USB DFU.

**Documentation** — changes to guides, theory documents, or installation
instructions. No hardware or firmware action required.

**[BREAKING]** — a change that requires action from anyone with an installed module.
Breaking changes are rare and are clearly marked.

---

*This project follows [Semantic Versioning](https://semver.org/). v1.0.0 will be
tagged when the hardware has been verified on a physical unit and the installation
guide is complete with photographs.*

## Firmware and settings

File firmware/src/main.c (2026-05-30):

/**
 * main.c — DSR-1 Startup, Clock Initialisation, and Main Loop
 *
 * WM-D6C Servo Replacement Module (DSR-1)
 * Hardware: STM32G0B1KBU6, bare-metal, no HAL, no RTOS
 *
 * Boot sequence (total time to servo loop: ~2ms):
 *
 *   t = 0        Power-on reset released, execution begins at reset vector
 *   t = ~0.3ms   clock_init(): HSI16 → PLL → 64 MHz system clock
 *   t = ~0.3ms   flash_load(): load saved settings from flash (or use defaults)
 *   t = ~0.5ms   adc_init(): GPIO + DMA + ADC1 continuous scan starts
 *   t = ~0.5ms   servo_init(): TIM2 input capture + TIM3 PWM + NVIC configured
 *   t = ~0.5ms   usb_cdc_init(): HSI48 + CRS + USB peripheral, DP pull-up asserted
 *   t = ~0.5ms   __enable_irq(): all interrupts unmasked
 *   t = ~2ms     First FG edge arrives, TIM2_IRQHandler fires, servo loop running
 *   t = ~300ms   Motor reaches operating speed, servo locked
 *
 * Main loop:
 *   Runs at maximum speed after interrupt overhead (~99.9% idle).
 *   Only responsibilities: service USB CDC (usb_cdc_poll) and execute WFI
 *   to yield CPU while waiting for the next interrupt.
 *   The servo loop runs entirely in TIM2_IRQHandler — the main loop never
 *   touches servo state directly.
 *
 * Interrupt priority hierarchy (see why-bare-metal.md §5.1):
 *   Priority 0 (highest): TIM2 capture — servo ISR, non-negotiable
 *   Priority 1:           USB — CDC data, enumeration
 *   Priority 2 (lowest):  SysTick (if used — currently unused)
 *
 * Motor safety at all times:
 *   TIM3 PWM defaults to 0% duty at reset — Q_LS (MMBT3904) is off.
 *   R9 (100kΩ to B+1) holds Q601 (2SB1013 PNP) base toward B+1 (6V),
 *   reverse-biasing Q601 (emitter at 10.8V) and keeping the motor off.
 *   The motor cannot run uncontrolled at any point in the boot sequence.
 */

#include "stm32g0xx.h"
#include <stdint.h>
#include "config.h"
#include "servo.h"
#include "adc.h"
#include "flash.h"
#include "usb_cdc.h"

/* Boot status flags — set during init, reported via USB CDC on first connection.
 * Passed explicitly to usb_cdc_set_boot_status() after USB init so the CDC
 * layer can report it as a banner when the host first connects. */

/* Called by startup_stm32g0b1xx.s before main(). Clock setup is handled
 * entirely by clock_init() below, so this can be a no-op. */
void SystemInit(void) {}

/* Called by newlib's __libc_init_array (invoked from startup) to run C++
 * static constructors. No C++ is used; stub satisfies the linker. */
void _init(void) {}

/* =========================================================================
 * clock_init()
 *
 * Brings the system clock from the power-on default (HSI16, 16 MHz) to
 * the target (HSI16 × PLL, 64 MHz).
 *
 * PLL configuration: HSI16 → PLLM=/1 → 16 MHz → PLLN=×8 → 128 MHz VCO
 *                    → PLLR=/2 → 64 MHz SYSCLK
 *
 * Flash latency must be set to 2 wait states BEFORE switching to 64 MHz.
 * Switching first then setting latency risks a read error from the flash
 * controller at the higher clock frequency.
 *
 * See usb-crystalless-operation.md §3.2 for full derivation.
 * ========================================================================= */
static void clock_init(void)
{
    /* Step 1: Ensure HSI16 is on and stable (it is the default on reset,
     * but be explicit to handle any edge case where it was disabled) */
    RCC->CR |= RCC_CR_HSION;
    while (!(RCC->CR & RCC_CR_HSIRDY)) { }

    /* Step 2: Configure PLL — must be done while PLL is off */
    RCC->PLLCFGR = RCC_PLLCFGR_PLLSRC_HSI          /* Source: HSI16       */
                 | (0U << RCC_PLLCFGR_PLLM_Pos)     /* PLLM = /1           */
                 | (8U << RCC_PLLCFGR_PLLN_Pos)     /* PLLN = ×8 (VCO=128MHz) */
                 | (1U << RCC_PLLCFGR_PLLR_Pos)     /* PLLR = /2 → 64 MHz */
                 | RCC_PLLCFGR_PLLREN;              /* Enable PLLR output  */

    /* Step 3: Enable PLL and wait for lock */
    RCC->CR |= RCC_CR_PLLON;
    while (!(RCC->CR & RCC_CR_PLLRDY)) { }

    /* Step 4: Set flash latency for 64 MHz BEFORE switching clock source.
     * At 64 MHz (VDD 3.3V, Range 1): 2 wait states required (RM0444 §3.3.4).
     * Enable prefetch and instruction cache for best performance. */
    FLASH->ACR = (2U << FLASH_ACR_LATENCY_Pos)
               | FLASH_ACR_PRFTEN
               | FLASH_ACR_ICEN;
    /* Verify latency was accepted before proceeding */
    while ((FLASH->ACR & FLASH_ACR_LATENCY) != (2U << FLASH_ACR_LATENCY_Pos)) { }

    /* Step 5: Switch system clock to PLLR output */
    RCC->CFGR = (RCC->CFGR & ~RCC_CFGR_SW) | RCC_CFGR_SW_1;  /* SW = 10: PLLRCLK */
    while ((RCC->CFGR & RCC_CFGR_SWS) != RCC_CFGR_SWS_1) { } /* Wait for switch */

    /* AHB prescaler = /1 (HCLK = SYSCLK = 64 MHz) — default, explicit for clarity */
    RCC->CFGR &= ~RCC_CFGR_HPRE;

    /* APB prescaler = /1 (PCLK = HCLK = 64 MHz) — default */
    RCC->CFGR &= ~RCC_CFGR_PPRE;
}

/* =========================================================================
 * main()
 * ========================================================================= */
int main(void)
{
    /* ---- 1. Clock init — must be first ---- */
    clock_init();

    /* ---- 2. Load settings from flash ----
     * Done before any peripheral init so that g_kp_q16, g_ki_q16, and
     * g_target_period hold the correct values when servo_init() runs.
     * If the flash block is absent or corrupt, compiled-in defaults from
     * config.h are used — but we capture the result so the USB CDC layer
     * can warn the user via the connection banner.
     * flash_load() is a read-only operation — no erase/write at this point.
     * We intentionally do NOT auto-save defaults on a corrupt block — the
     * user should verify settings via USB CDC before committing to flash. */
    FlashResult flash_status = flash_load();

    /* ---- 3. ADC init — before servo_init() ----
     * The ADC DMA scan starts immediately. By the time the first FG edge
     * arrives (~2ms), at least one complete 3-channel conversion has
     * completed and g_adc_raw[] holds valid pot readings. */
    adc_init();

    /* ---- 4. Servo init ----
     * Configures TIM2 input capture, TIM3 PWM output (pre-loaded to
     * DAC_CENTER), and registers TIM2 in NVIC at priority 0.
     * The TIM2 ISR will not fire until __enable_irq() below. */
    servo_init();

    /* ---- 5. USB CDC init ----
     * Configures HSI48, CRS, USB peripheral, and GPIO for PA11/PA12.
     * Asserts DP pull-up — the host will begin enumeration as soon as
     * __enable_irq() unmasks the USB interrupt.
     * USB interrupt registered in NVIC at priority 1. */
    usb_cdc_init();

    /* Pass flash load result to USB CDC so it can report it in the
     * connection banner. Done after usb_cdc_init() but before
     * __enable_irq() — no race possible yet. */
    usb_cdc_set_boot_status(flash_status);

    /* ---- 6. Enable global interrupts ----
     * From this point:
     *   - TIM2 ISR fires on every FG rising edge (servo loop running)
     *   - USB ISR fires on enumeration and CDC data transfers
     * Order of steps 3–5 above ensures all peripherals are fully configured
     * before any interrupt can fire. */
    __enable_irq();

    /* ---- 7. Main loop ----
     * The servo loop runs entirely in TIM2_IRQHandler. The main loop has
     * one job: service USB CDC. Everything else is interrupt-driven.
     *
     * WFI behaviour:
     *   We only call __WFI() when there is genuinely nothing pending —
     *   no bytes in the receive buffer and continuous telemetry is off.
     *   This prevents the pathological case where an interrupt wakes the
     *   CPU, its handler queues data into rx_buf[], the handler returns,
     *   and the CPU immediately sleeps again before usb_cdc_poll() has
     *   had a chance to drain the buffer.
     *
     *   If there is pending work (bytes to drain or telemetry to send),
     *   the loop spins at full speed. When truly idle, WFI reduces current
     *   from ~9mA to ~2mA. TIM2 input capture is hardware-triggered and
     *   wakes the CPU within one clock cycle regardless of sleep state. */
    for (;;) {
        usb_cdc_poll();

        /* Only sleep if there is genuinely nothing pending */
        if (usb_cdc_idle()) {
            __WFI();
        }
    }

    /* Unreachable — suppress compiler warning */
    return 0;
}

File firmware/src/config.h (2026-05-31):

/**
 * config.h — DSR-1 Tunable Constants
 *
 * WM-D6C Servo Replacement Module (DSR-1)
 *
 * THIS IS THE ONLY FILE YOU SHOULD NEED TO EDIT FOR NORMAL CONFIGURATION.
 *
 * All machine-specific values, gain constants, hardware limits, and feature
 * selection flags live here. Edit this file and rebuild — do not scatter
 * magic numbers through the source files.
 *
 * To convert between floating-point and Q16:
 *   Q16 = (int32_t)(float_value * 65536)
 *   float = Q16_value / 65536.0
 *
 * Motor output stage: PWM + RC filter + NPN level-shift via PA6 (TIM3_CH1).
 * Q601 on WM-D6C serial 72795 is a 2SB1013 PNP transistor with emitter at
 * B+3 (10.8V). The base operating range is well above 3.3V, ruling out direct
 * DAC drive. The NPN level-shift stage (Q_LS MMBT3904, R7-R9) is the sole
 * motor output topology for this build.
 *
 * See fixed-point-arithmetic.md for full derivation and overflow analysis.
 * See digital-pll-servo.md for servo algorithm context.
 * See tools/calibration/fg-period-calculator.py for conversion helpers.
 */

#ifndef CONFIG_H
#define CONFIG_H

#include <stdint.h>

/* =========================================================================
 * SECTION 1 — SYSTEM CLOCK
 *
 * Do not change unless you have modified clock_init() in main.c.
 * All timing constants below are derived from this value.
 * ========================================================================= */

#define SYSCLK_HZ           64000000UL   /* HSI16 × PLL → 64 MHz            */

/* =========================================================================
 * SECTION 2 — FG TARGET SPEED
 *
 * TARGET_PERIOD_DEFAULT is the FG pulse period in 64 MHz clock ticks that
 * corresponds to correct tape transport speed (4.75 cm/s).
 *
 * *** THIS VALUE MUST BE MEASURED ON THE BENCH ***
 * Use test tape WS-48B: correct speed = 3 kHz on LINE OUT.
 * Measure FG901 pulse frequency with an oscilloscope or logic analyser at
 * that speed. Then:
 *   TARGET_PERIOD_DEFAULT = SYSCLK_HZ / FG_target_Hz
 *
 * The placeholder value below assumes 2500 Hz FG rate (25,600 ticks).
 * This is a reasonable starting estimate but will NOT be correct for your
 * specific unit. Do not use this value for final calibration.
 *
 * Example: if bench measurement gives FG = 2487 Hz:
 *   TARGET_PERIOD_DEFAULT = 64000000 / 2487 = 25,729
 * ========================================================================= */

#define FG_TARGET_HZ_NOMINAL    2500UL
#define TARGET_PERIOD_DEFAULT   (SYSCLK_HZ / FG_TARGET_HZ_NOMINAL)  /* 25,600 ticks */

/* Safety bounds on adjusted target (after pot trim is applied).
 * ADJUSTED_TARGET_MIN = half nominal (motor cannot run at 2× speed physically)
 * ADJUSTED_TARGET_MAX = double nominal (motor cannot run at 0.5× speed usefully) */
#define ADJUSTED_TARGET_MIN     (TARGET_PERIOD_DEFAULT / 2)   /* 12,800 ticks */
#define ADJUSTED_TARGET_MAX     (TARGET_PERIOD_DEFAULT * 2)   /* 51,200 ticks */

/* =========================================================================
 * SECTION 3 — PI GAIN CONSTANTS
 *
 * Stored in Q16 fixed-point format (value × 65536).
 * Starting values are engineering estimates — tune on bench with test tape.
 * Use USB CDC commands p+/p-/i+/i- for live adjustment; save with 's'.
 *
 * Kp = 0.15  →  KP_Q16 = (int32_t)(0.15 × 65536) = 9830
 * Ki = 0.008 →  KI_Q16 = (int32_t)(0.008 × 65536) = 524
 *
 * Tuning guidance (see digital-pll-servo.md §4.3):
 *   Increase Kp → faster response, risk of audible speed oscillation
 *   Decrease Kp → sluggish response, slow recovery from tape tension changes
 *   Increase Ki → faster correction of steady-state drift, risk of low-freq hunt
 *   Decrease Ki → slower drift correction, longer time to lock after start
 * ========================================================================= */

#define KP_Q16_DEFAULT          9830    /* Kp = 0.1500 */
#define KI_Q16_DEFAULT          524     /* Ki = 0.0080 */

/* USB CDC step sizes for p+/p-/i+/i- commands */
#define KP_Q16_STEP             655     /* ≈ +0.01 in float  (655 / 65536 = 0.00999) */
#define KI_Q16_STEP             66      /* ≈ +0.001 in float (66  / 65536 = 0.00101) */

/* Safety limits — gain constants are clamped to these ranges.
 * Prevents runaway if USB CDC receives corrupted input. */
#define KP_Q16_MIN              0
#define KP_Q16_MAX              65536   /* Kp = 1.0 — well above any practical value */
#define KI_Q16_MIN              0
#define KI_Q16_MAX              6554    /* Ki = 0.1 — well above any practical value  */
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

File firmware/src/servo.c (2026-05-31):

/**
 * servo.c — DSR-1 Capstan Servo
 *
 * WM-D6C Servo Replacement Module (DSR-1)
 * Hardware: STM32G0B1KBU6, bare-metal, no HAL, no RTOS
 *
 * Peripherals owned by this file:
 *   TIM2   — free-running 32-bit counter at 64 MHz, CH1 input capture on PA0
 *             captures rising edges of the FG901 signal
 *   TIM3   — channel 1 on PA6, PWM output to NPN level-shift stage (Q_LS)
 *
 * Motor output stage:
 *   TIM3 CH1 PWM → R7/C8 RC filter → Q_LS (MMBT3904 NPN) base
 *   Q_LS collector pulls Q601 (2SB1013 PNP) base toward GND via R9.
 *   R9 (100kΩ to B+1) holds Q601 base high (motor off) when Q_LS is off.
 *   At reset/boot, TIM3 PWM defaults to 0% duty — Q_LS off — motor off.
 *
 * PI control convention:
 *   Error = measured_period - target_period
 *   Positive error  → motor running too slow (period longer than target)
 *   Q601 is PNP with emitter at B+3; R9 (100kΩ to B+1) holds base above
 *   emitter (motor off) when Q_LS is off. B+1 > B+3 bias confirmed on bench.
 *   Lower PWM → Q_LS less drive → Q601 base rises toward B+1 → Veb increases
 *   → more collector current → faster motor. (DAC_MIN = near-full drive.)
 *   Therefore: positive error → subtract from DAC_CENTER → lower PWM → faster
 *
 * Fixed-point arithmetic:
 *   All gain constants stored in Q16 format (value × 65536).
 *   Multiplication result right-shifted 16 to recover integer units.
 *   No software floating-point in ISR — single-cycle barrel shift only.
 *
 * See fixed-point-arithmetic.md and digital-pll-servo.md for full derivation.
 */

#include "stm32g0xx.h"
#include <stdint.h>
#include "config.h"
#include "servo.h"
#include "adc.h"

/* -------------------------------------------------------------------------
 * Module-private state
 * All variables shared between ISR and main loop are volatile.
 * The ISR is the only writer; main loop reads for telemetry.
 * ------------------------------------------------------------------------- */

static volatile uint32_t last_capture   = 0;
static volatile int32_t  integral       = 0;

/* Public telemetry — written by ISR, read by usb_cdc.c */
volatile ServoTelemetry g_telemetry;

/* Gain constants — written by usb_cdc.c command handler (main loop only),
 * read by ISR. Write must be atomic on Cortex-M0+: 32-bit aligned store is
 * single-instruction and therefore inherently atomic. Safe without a mutex. */
volatile int32_t g_kp_q16        = KP_Q16_DEFAULT;
volatile int32_t g_ki_q16        = KI_Q16_DEFAULT;
volatile uint32_t g_target_period = TARGET_PERIOD_DEFAULT;

/* -------------------------------------------------------------------------
 * servo_init()
 *
 * Called once from main() after clock init.
 * Configures TIM2 input capture, TIM3 PWM output, and NVIC priority.
 * Does NOT start the servo loop — that begins automatically on the first
 * FG edge after this function returns.
 * ------------------------------------------------------------------------- */
void servo_init(void)
{
    /* ---- GPIO ---- */

    /* PA0: TIM2_CH1 input capture (AF2), FG901 signal   — AF2 per DS §4 Table 12
     * PA6: TIM3_CH1 PWM output   (AF1), NPN level-shift stage drive */

    RCC->IOPENR |= RCC_IOPENR_GPIOAEN;

    /* PA0 — alternate function AF2 (TIM2_CH1); was erroneously AF1 (finding 5.2) */
    GPIOA->MODER   = (GPIOA->MODER  & ~(3U << (0*2))) | (2U << (0*2));
    GPIOA->AFR[0]  = (GPIOA->AFR[0] & ~(0xFU << (0*4))) | (2U << (0*4));

    /* PA6 — alternate function AF1 (TIM3_CH1) */
    GPIOA->MODER   = (GPIOA->MODER  & ~(3U << (6*2))) | (2U << (6*2));
    GPIOA->AFR[0]  = (GPIOA->AFR[0] & ~(0xFU << (6*4))) | (1U << (6*4));

    /* ---- TIM2: free-running 32-bit counter, input capture on CH1 ---- */

    RCC->APBENR1 |= RCC_APBENR1_TIM2EN;

    TIM2->PSC   = 0;           /* No prescaler: 1 tick = 15.625 ns at 64 MHz */
    TIM2->ARR   = 0xFFFFFFFF;  /* Full 32-bit range, free-running            */

    /* CC1 configured as input, mapped to TI1 (PA0), no input filter */
    TIM2->CCMR1 = (1U << TIM_CCMR1_CC1S_Pos); /* CC1S = 01: CH1 input on TI1 */
    TIM2->CCER  = TIM_CCER_CC1E;              /* Enable capture, rising edge  */

    TIM2->DIER = TIM_DIER_CC1IE;
    TIM2->SR   = 0;
    TIM2->CR1  = TIM_CR1_CEN;

    /* ---- TIM3 CH1: PWM for NPN level-shift motor output ---- */

    RCC->APBENR1 |= RCC_APBENR1_TIM3EN;

    /* 64 MHz / (PSC+1) / ARR = PWM frequency.
     * PSC = 0, ARR = 4095: PWM frequency = 64 MHz / 4096 ≈ 15.6 kHz
     * Well above audio band, well below FG capture interference threshold. */
    TIM3->PSC   = 0;
    TIM3->ARR   = 4095;

    /* CH1 in PWM mode 1: output high while CNT < CCR1 */
    TIM3->CCMR1 = (6U << TIM_CCMR1_OC1M_Pos) | TIM_CCMR1_OC1PE;
    TIM3->CCER  = TIM_CCER_CC1E;

    /* Pre-load at mid-scale. At 0% duty Q_LS is off and R9 holds Q601 base
     * toward B+1 — motor off. Mid-scale is a safe starting drive point once
     * the servo loop takes over. */
    TIM3->CCR1  = DAC_CENTER;
    TIM3->CR1   = TIM_CR1_ARPE | TIM_CR1_CEN;

    /* ---- NVIC ---- */

    /* TIM2 interrupt at highest priority (0).
     * This is non-negotiable — see why-bare-metal.md §5.1.
     * The servo ISR must preempt all other interrupts including USB. */
    NVIC_SetPriority(TIM2_IRQn, 0);
    NVIC_EnableIRQ(TIM2_IRQn);
}
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

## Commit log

2026-05-27 Create DATASHEET_LINKS.md
    # Datasheet Links — see docs for full index
2026-05-27 Add Creative Commons Attribution 4.0 License
    This file contains the full text of the Creative Commons Attribution 4.0 International Public License, outlining the terms and conditions for using licensed material.
2026-05-27 Create Datasheet_links.md for component references
    Added a comprehensive datasheet reference document for various components used in the wmd6c-servo DSR-1 project, including MCUs, power management, and discrete semiconductors.
2026-05-27 Update fmt.Println message from 'Hello' to 'Goodbye'
2026-05-28 added base KiCad project. removed placeholder file.
    [DSR-1.kicad_pcb, DSR-1.kicad_sch]
2026-05-28 added hierarcal sheets
    [Connectors.kicad_sch, DSR-1.kicad_sch, Power input zone.kicad_sch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]
2026-05-28 added sheet labels and created power symbold for B+1 and B+3
    [Connectors.kicad_sch, DSR-1.kicad_sch, Power input zone.kicad_sch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]
2026-05-28 remove .history submodule and fix gitignore pattern
    .history was accidentally committed as a git submodule with no
    .gitmodules entry, causing persistent 'untracked content' errors.
    Removed from index and broadened gitignore to **/.history/ to
    cover nested paths like hardware/kicad/DSR-1/.history.
2026-05-28 deleted extra sheet from schematic
2026-05-28 Add DSR-1 KiCad 10 Schematic Implementation Guide and update datasheet links
    - Introduced comprehensive guide for translating the DSR-1 design into a KiCad 10 schematic, covering all sheets and components.
    - Detailed compatibility scope for WM-D6C / TC-D6C production run, including servo circuit families and PCB construction generations.
    - Listed prerequisites for KiCad setup and provided a shortcut reference for ease of use.
    - Defined hierarchical label rules and sheet architecture for schematic organization.
    - Documented each sheet's purpose, components, and connections, ensuring clarity for future reference.
    - Updated datasheet links for Sony WM-D6C service manuals, including specific ver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
    [config.h, main.c, servo.c]
2026-05-28 Update documentation for motor output stage and Q601 transistor specifications across multiple files
2026-05-29 Updated schematics
    [Connectors.kicad_sch, DSR-1.kicad_sch, Power input zone.kicad_sch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]
2026-05-29 updated schematics and changed photo name
    [Connectors.kicad_sch, DSR-1.kicad_sch, Power input zone.kicad_sch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]
2026-05-29 updated project symbol library ans started routing power input schematic
    [Power input zone.kicad_sch]
2026-05-30 Add startup file for STM32G0B1xx devices
    This commit introduces the startup assembly file `startup_stm32g0b1xx.s` for STM32G0B1xx microcontrollers. The file includes the vector table, reset handler, and default interrupt handlers. It sets up the initial stack pointer, copies the data segment from flash to SRAM, zeroes the BSS segment, and calls the main application entry point. Additionally, weak aliases for each exception handler are provided to default to a common handler.
    [adc.c, flash.c, main.c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]
2026-05-30 Add Renode simulation support for DSR-1 firmware
    - Introduced README.md for DSR-1 Renode simulation setup and usage instructions.
    - Created platform definition for STM32G0B1KBU6 in `stm32g0b1kbu6.repl`, correcting RAM size, CPU type, and systick frequency.
    - Added simulation script `dsr1.resc` to initialize the DSR-1 environment and load the firmware.
    - Implemented FG signal injection helper script `fg-gen.resc` for testing servo control via Renode.
    - Developed automated tests for servo loop behavior in `servo_loop.robot`, covering various scenarios including nominal speed, slow/fast responses, and PWM output clamping.
    - Updated `main.c` with a stub for C++ static constructors to satisfy lin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
    [main.c]
2026-05-30 Update Renode simulation scripts and README for ADC handling and IRQ injection
2026-05-31 Fix flash settings address, update ADC initialization, and improve USB handling
    - Updated the flash settings address from 0x0801F000 to 0x0801F800 in multiple files to ensure proper preservation across DFU updates.
    - Added ADC clock selection before calibration in adc.c to comply with RM0444 requirements.
    - Enhanced USB handling in usb_cdc.c, including updates to endpoint configurations and interrupt handling for the STM32G0B1 USB IP.
    - Improved comments and documentation throughout the code for clarity and accuracy.
    [adc.c, config.h, flash.c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]
2026-05-31 Completed Power Input Sheet Variant A
    [Power input zone.kicad_sch]
2026-05-31 Refactor code structure for improved readability and maintainability
    [Power input zone.kicad_sch]
2026-05-31 Completed microcontroller schematic
    [Connectors.kicad_sch, Power input zone.kicad_sch, Power management.kicad_sch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]
2026-06-01 completed schematics through sheet 5.
    [Connectors.kicad_sch, DSR-1.kicad_sch, STM32G0C1 and decoupling.kicad_sch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]
2026-06-01 Adjusted visual layout of sheet 5
    [Signal conditioning.kicad_sch]
2026-06-04 Update position of BRING-UP ORDER text in Power management schematic for better visibility
    [DSR-1.kicad_sch, Power management.kicad_sch]
2026-06-04 Cleaned up the schematic a little bit.
    [DSR-1.kicad_sch]
2026-06-07 Update documentation and firmware references for STM32G0C1KCU6 migration
    - Updated references from STM32G0B1KBU6 to STM32G0C1KCU6 in USB crystalless operation, USB PD without firmware, and other related documents.
    - Adjusted terminology in the context of PWM output and DAC to reflect the new hardware architecture.
    - Revised verification checklists and motor drive characterization documents to align with the new microcontroller specifications.
    - Updated simulation and firmware README files to indicate ongoing migration to STM32G0C1KCU6 while retaining legacy filenames.
2026-06-07 added power board kicad project and moved power schematic from dsr1 to new project.
    [wm-d6c-power-board.kicad_pcb, wm-d6c-power-board.kicad_sch]
2026-06-07 updated schematic guide and dsr-1 schematic
    [DSR-1.kicad_sch]
2026-06-07 updated schematic guide
2026-11-09 Rev A schematics for both boards; retarget firmware to STM32G0C1
    Schematics (generated by tools/, ERC 0 errors/0 warnings, netlist-verified)
    - Servo Control Board: drop the old wall-power front end (IP2721, barrel
    jack, AP63203) and the 9V_PD/GND short; rewire the MT3608 boost; add the
    CP304, Sony servo, pots/S601, LED, telemetry, SWD and USB-entry
    connectors, CC termination, input dividers and 25 test points.
    - Power Board: complete BQ24074 charger, 1S3P cells, DW01A + FS8205A
    protection, TPS63070 6.0 V B+1 regulator, telemetry and test points;
    new project library (TPS63070RNM, FS8205A, B+1) and sym-lib-table.
    - tools/kicad_sch.py + generators + self-test; PDFs in schematic-pdfs/.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
2026-11-09 Add .gitattributes to normalise line endings to LF
    Files checked out or edited on Windows were showing as modified only
    because of CRLF line endings. Store and check out LF everywhere, keep
    KiCad files as LF text, and mark PDFs, Office files, images and build
    binaries as binary.
